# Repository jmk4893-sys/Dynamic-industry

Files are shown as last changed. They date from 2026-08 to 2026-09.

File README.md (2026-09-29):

# Dynamic-industry

Dynamic industry Development

## 태양광 셀 은(Ag) 회수 부유선별 설비

폐 태양광 모듈(c-Si)에서 박리한 셀 분획으로부터 **은(Ag)** 을 부유선별로 농축하는
설비의 설계와 계산 코드. 셀 분획을 공급하는 상류 분리설비(DG-HK60)는
[3D 운전 콘솔](docs/drawings/pv-delamination-3d.html)로 별도 정리했다.

- 평균 **0.30 t/h**, 최대 **0.50 t/h** (건조 고체 기준)
- **세척수 bias 연속 부선조 1단, Ø350 mm × 라이저 2.4 m** (대안: 기계식 러퍼·스캐빈저·클리너 3단)
- Ag 회수율 **99.7 %**, 정광 **6.36 kg/h @ 46.3 wt% Ag** (농축비 78배)
- 기액 체류시간 **1 분**, 설치 전력 **6.52 kW** (탈수 보조설비 포함)
- 황화제·pH 조정제·억제제 없음 — 약제는 포수제·촉진제·기포제 3종뿐

### 설계 근거

실증 논문 두 편의 데이터를 1차 근거로 삼고, 모델이 그 실험값을 재현하도록 보정했다.
`tests/test_references.py` 가 재현성을 검증하므로, 설계 기준을 고쳐 문헌과 어긋나면
테스트가 실패한다.

1. Saffarian, Galvin, Firouzi, *Minerals Engineering* **242** (2026) 110189 — 회분식 실증
2. Saffarian, Galvin, Firouzi, ChemRxiv preprint (2026), doi:10.26434/chemrxiv.15003814/v1 — 연속 실증

> [2] 는 프리프린트이며 저자들이 호주 가출원(No. 2025902821)을 제출한 상태다.
> 상업화 전 실시권 검토가 필요하다.

### 문서

| 문서 | 내용 |
|---|---|
| [docs/flotation-separator-design.md](docs/flotation-separator-design.md) | 설계 사양서 — 근거, 두 안, 계장·안전, 시운전 계획 |
| [docs/design-calculation.md](docs/design-calculation.md) | 설계 계산서 (코드에서 자동 생성) |
| [docs/drawings/ag-flotation-drawings.html](docs/drawings/ag-flotation-drawings.html) | **설계도 7매** — 공정 흐름도(필터프레스 라인 포함), 부선조 상세 단면도, 장치 대안 비교도, 중공축 급기 상세, 셀별 상세 3매 (브라우저로 열 것) |
| [docs/drawings/ag-flotation-3d.html](docs/drawings/ag-flotation-3d.html) | **3D 조립·분해도** — 러퍼·스캐빈저·클리너 3단 스키드 + 농축조·필터프레스, 셀당 20개 부품 분해 (브라우저로 열 것) |
| [docs/drawings/pv-delamination-3d.html](docs/drawings/pv-delamination-3d.html) | **DG-HK60 3D 운전 콘솔** — 부선 공정에 셀 분획을 공급하는 상류 분리설비. 5단 밀폐 IR 캐리지 순환, 이동 계단 칼날(SHK-101) 박리 — 셀모듈과 백시트를 유리에서 한 장으로, 일곱 조각이 따로 떠서 유리를 따라간다(칼날 모듈 추종), 15단계 공정 재생, 컷어웨이·분해도, 전기·PLC·제작도면 15종, **부품도 169장 · 모듈 조립도 13장**, 열수지 계산기 (브라우저로 열 것) |
| [docs/dg-hk60-rfq.html](docs/dg-hk60-rfq.html) | **DG-HK60 상세설계 기술사양서 (RFQ)** — 상세설계 용역 발주용. 요구성능·설계기준·기계/전기/안전 요구사항·납품물·FAT/SAT·입찰자 확인사항 16건 — 열린 15건 · OI-11 해소 (브라우저로 열 것, A4 인쇄 가능) |
| [docs/dg-hk60-fab-spec.html](docs/dg-hk60-fab-spec.html) | **DG-HK60C 제작 지침서 (FAB-001)** — 볼트 등급·체결력·조임토크, 용접 각장, 부재 판두께·재질, 기초 앵커 매입깊이·연단거리를 하중에서 유도한 문서. 접합부 11개소·부재 27종·앵커 6개소·ITP 16단계 (브라우저로 열 것, A4 인쇄 가능) |
| [docs/dg-hk60-assembly.html](docs/dg-hk60-assembly.html) | **DG-HK60C 조립 지침서 (ASM-001)** — 도면을 처음 보는 사람이 조립도·부품도만으로 세울 수 있게 쓴 문서. 안전·공구·도면 읽는 법·볼트 조이는 법·모듈 사이의 순서·모듈별 67단계 (부품 카탈로그에서 생성) |
| [docs/dg-hk60-procurement.html](docs/dg-hk60-procurement.html) | **DG-HK60C 조달 지침서 (PRC-001)** — 자재 발주표(1차원 절단 배치를 푼 정척 본수·시트 매수) · 운반 분할(세우는 순서를 따르는 차수표) · 구매품 사양 60종 (부품 카탈로그에서 생성) |
| [docs/dg-hk60-analysis.html](docs/dg-hk60-analysis.html) | **DG-HK60C 구조·열해석 보고서 (CAL-001)** — 직접강성법 프레임, 1차원 과도 열전도, **IR 뱅크 복사 유속 + 면내 2차원 전도**, **램프 지지·관통 상세**, **정상상태 열수지**, **칼날 모듈 추종**(패드 평면도가 만드는 유리 굴곡 · 몬테카를로). 닫힌해 15건으로 해석기를 검증하고 구조 14건·열 13건·IR 8건·지지 7건·수지 8건·에어록 8건을 푼 뒤, 해석이 만든 요구 26건과 **해석이 못 보는 것**을 적었다 (여섯 해석 모듈에서 생성) |
| [docs/dg-hk60-pilot.html](docs/dg-hk60-pilot.html) | **DG-HK60C 파일럿 시험 계획서 (PIL-001)** — 온도–박리력 곡선·칼날 수명·유리 수율·면내 온도 균일도·열수지. 시료 수를 요구정밀도에서 거꾸로 풀어(t 분위수·Clopper–Pearson) 총 454장·2단계로 잡았다 (계획 모델에서 생성) |
| [docs/dg-hk120-twin-cell.html](docs/dg-hk120-twin-cell.html) | **DG-HK120C 트윈 셀 검토서** — 1챔버·2분리셀(계단 칼날) 수평병렬로 처리량을 배로 올리는 안의 배치·전력·인터록 검토 (브라우저로 열 것) |

## MP-50 염수 밀도분리 파일럿 장치

폐태양광 후처리 블랙파우더에서 **EVA·백시트를 실리콘 분말로부터 걷어내는** 소형
파일럿. 세 재질의 입경이 31~75 µm 로 겹쳐 체로는 나눌 수 없으므로, 염수(NaCl
0~18 wt%)의 밀도를 세 재질의 유효밀도 사이에 놓고 나눈다. 임펠러와 급기는
**분산 수단이지 분리 수단이 아니다** — 둘을 동시에 정지시킨 뒤의 자연 부상·침강이
분리다.

- 동체 **Ø400 ID × H600**, 원뿔 60° · 전용적 **89.86 L**, 운전 장입 **61.4 L**
- 아세이 A~K **11계통 · 부품 220개**, 건조질량 **151 kg**
- 교반축 Ø25 SUS316L, Ø300 4PBT45° 임펠러 2단, 배플 4매, 콘 급기 분산링
- 제어반 J-06 — 0.55 kW VFD, 감속비 1/10, **CR1 접점 하나가 임펠러와 급기를 동시에 끊는다**

### 동시 차단은 운용 규칙이 아니라 회로다

임펠러와 급기가 몇 초라도 어긋나 멎으면 잔류 와류나 잔류 기포가 층분리를
흐트러뜨려 **정치 t=0 이 정의되지 않는다**. 그러면 DOE 의 정치시간 축이 통째로
못 쓰게 된다. 그래서 제어반은 셋을 구조로 강제한다.

- **운전 릴레이 CR1 의 접점 하나**가 VFD RUN·급기 솔레노이드·로거 t=0 마크를 함께
  문다. 버튼을 둘로 나누면 사람이 누르는 순서가 데이터에 섞인다.
- **분산시간은 타이머(TIM1)가 끊는다.** 수동 버튼은 조기 차단용으로만 병치한다 —
  조건표대로 돌리면 배치마다 분산시간이 같다.
- **VFD 정지방식은 프리런**이다. 램프 정지는 감속하는 동안에도 저어서 t=0 을 흐린다.
- 급기 솔레노이드는 **NC** 라 소자되면 닫힌다. 정전이나 배선 단선에서도 공기가
  들어가지 않는다.

감속비는 여기서 갈린다. 표준 감속비 가운데 축 150 rpm 을 낼 수 있는 것은 **1/10
뿐**이고, 1/20 은 60 Hz 에서도 87 rpm 에 그친다 — 이것이 연구문서가 적은 상한
90 rpm 의 정체로 보인다 ([`control.py`](src/mp50_separator/control.py)).

### 원본 도면 그대로는 제작이 되지 않는다

치수가 세 문서에 흩어져 있고 셋이 서로 다르다 — 연구문서 Rev.0, 도면
MP-50-P0-001, 도면 MP50-DR-000. 충돌 8건을 정리했고 그중 **2건은 그대로 두면
조립 자체가 불가능**하다.

| 번호 | 항목 | 원본 | 문제 |
|---|---|---|---|
| **C1** | 원뿔 높이 | H150 + 60° | Ø400 에서 Ø38 로 닫히지 않는다 (313.5 필요) |
| **C2** | 배플 폭 | 80 × 4매 | 안쪽 모서리 R114 가 Ø300 임펠러 팁 R150 과 **36 mm 겹쳐 축이 돌지 않는다** |

해결 근거는 [`conflicts.py`](src/mp50_separator/conflicts.py) 와 제작도면의
'원본 치수 충돌과 해결 근거' 절에 남겼다. C1 은 연구문서의 H346 을 **가상 정점높이**로
읽으면 동체 상단 Z946 · 커버 상면 Z951 · 전용적 89.9 L 가 한 원점에서 동시에
맞아떨어지므로 확정했고, C2 는 임펠러 Ø300 이 세 문서에 모두 같고 DOE·동력·Njs
모델이 그 위에 서 있으므로 배플 쪽을 35 mm 로 줄였다.

### 문서

| 문서 | 내용 |
|---|---|
| [docs/drawings/mp50-fabrication-drawings.html](docs/drawings/mp50-fabrication-drawings.html) | **제작도면 A3 17매** — 기준좌표·공차, 전체 조립도, 아세이 A~K, 동체·원뿔 전개도, 노즐표, 용접·검사 기준, **제어반 J-06 결선도 2매**. 손으로 적은 치수가 없다 (브라우저로 열 것) |
| [docs/drawings/mp50-part-drawings.html](docs/drawings/mp50-part-drawings.html) | **부품 상세도면 A3 29매** — 제작품 33종을 27장에 담았다 (소물은 합본). 장마다 소재 규격, 완성 치수, 기하공차, 표면, 가공 순서, 검사. 규격·구매품은 도면 대신 명세 한 장 (브라우저로 열 것) |
| [docs/drawings/mp50-3d.html](docs/drawings/mp50-3d.html) | **3D 분해 · 컷어웨이 · 부품 단독 보기 콘솔** — 아세이별 분해, 단면 컷어웨이, 부품 하나만 떼어 보기, 분산→동시 정지→자연 층분리 재생. 입자는 검증 모듈과 같은 Stokes 식으로 움직인다 (브라우저로 열 것) |
| [docs/cad/](docs/cad/) | **CAD 파일 — 절단 DXF 33, 가공도 DXF 33, 3D STEP 33** — 레이저 CAM 이 그대로 먹는 1:1 윤곽, A3 가공도, 해석면 솔리드. 절단 길이 합계 약 44 m |
| [docs/mp50-fabrication-spec.md](docs/mp50-fabrication-spec.md) | 제작 기준 요약 (코드에서 자동 생성) |

### 도면에서 CAD 로

HTML 부품도는 사람이 읽는 것이고, `docs/cad/` 는 **기계가 읽는 것**이다. 같은
기하에서 나오므로 둘이 어긋날 수 없다.

- `dxf/cut/` — 절단 윤곽만. 1:1, 글자 한 자 없음, 원점은 소재 왼쪽 아래.
  레이저 오퍼레이터가 열어 그대로 자른다.
- `dxf/dwg/` — A3 가공도. 틀·표제란·치수·구멍 좌표표·절곡표·주기.
- `step/` — 3D 솔리드 (AP214). 평면·원통·원뿔 **해석면**이라 CAM 이 지름과
  축을 읽는다. 메시가 아니다.

DXF 는 R12(AC1009)·cp949 라 한국 현장 CAD 가 그대로 연다. STEP 33 개 전부를
OpenCascade 로 다시 읽어 **유효 솔리드**이고 부피가 해석값과 **0.0000 %** 차인
것을 확인했다. 시험은 외부 라이브러리 없이 파일을 되읽어 윤곽 폐합, 부호 방향,
소재 수용 여부, 모서리가 정확히 두 면에 쓰였는지를 본다.

CAD 를 세우면서 부품표의 결함 두 개가 드러났다.

- **각관 질량을 둥근 관 식으로 셌다.** □40 × t2 의 단면은 304 mm² 인데 원형
  식이 π/4 를 곱해 239 mm² 로 21 % 가볍게 나왔다. 프레임 18 본이 전부 각관이라
  아세이 H 가 23.3 → 27.9 kg, 건조 총계가 145.9 → **150.6 kg** 으로 늘었다.
- **동체 세로이음이 N1 급광 노즐을 지났다.** 전개 원점을 θ0 에 두면 노즐
  구멍이 평판 끝에 걸쳐 반쪽씩 잘린다. 이음선을 노즐이 없는 **θ135°** 로
  옮겼다 — 가장 가까운 노즐까지 158 mm 떨어진다.

### 설계 검증에서 나온 것

검증 14건 중 조립 항목은 전부 통과했고, 기능 항목 2건이 WARN 이다. 둘 다
**장치가 아니라 시험계획을 고치라**는 뜻이다.

- **CHK-05** Zwietering Njs 가 135 rpm 인데 감속기 상한이 90 rpm 이라 여유가 없다 →
  최고속도 150 rpm 확보 권고 (축·동력·위험속도는 150 rpm 으로 검증했다)
- **CHK-10** 정치 600 s 로는 31 µm 백시트가 1 % 만 부상한다. Stokes 는 지름의
  제곱으로 가므로 미세분은 시간이 제곱으로 든다 → 정치시간 격자를 600~3600 s 로
  넓히고, 염도 격자에 22/26 wt% 를 넣을 것 (포화까지 올리면 상승속도 2.7 배).
  단 포화 염수까지 갈 경우 동체는 SUS304 가 아니라 SUS316L 이어야 한다.

### 사용법

```bash
PYTHONPATH=src python -m mp50_separator                          # 제작 기준 출력
PYTHONPATH=src python -m mp50_separator -o docs/mp50-fabrication-spec.md
python tools/mp50_drawings.py                                    # 아세이 제작도면 15매
python tools/mp50_parts.py                                       # 부품 상세도면 29매
```

### 구조

```
src/mp50_separator/
  geometry.py    Z 기준좌표계 · 원뿔 폐합 · 용적 · 노즐 (여기만 고치면 된다)
  components.py  아세이 A~K 부품표 — 질량은 기하에서 계산한다
  conflicts.py   원본 3종의 치수 충돌 8건과 해결 근거
  checks.py      제작성·기능성 검증 14건 (조립 / 기능)
tools/
  mp50_drawings.py   기하에서 아세이 제작도면 HTML 을 생성
  mp50_parts.py      제작품마다 부품 상세도면 HTML 을 생성
  _mp50_draft.py     ISO 128 제도 프리미티브 (두 생성기 공용)
```

도면은 둘 다 **코드에서 생성**한다. 손으로 고치면 `tests/test_mp50_drawings.py`
와 `tests/test_mp50_parts.py` 의 재생성 검사가 깨진다. 부품도는 `components.py`
의 조달 구분(제작/규격/구매/가공)을 그대로 따르므로, 제작품을 하나 추가하고
도면을 잊으면 생성 자체가 실패한다.

### 사용법

패키지가 `src/` 레이아웃이므로 설치 없이 실행할 때는 `PYTHONPATH=src` 를 붙인다.

```bash
PYTHONPATH=src python -m flotation_design                               # 계산서 출력
PYTHONPATH=src python -m flotation_design -o docs/design-calculation.md # 파일로 저장
PYTHONPATH=src python -m flotation_design --peak-tph 0.6                # 처리량 변경
python -m unittest discover -s tests -t .                               # 테스트 (1,207건)

# 부품 카탈로그 — 형상·치수·재질에서 질량과 자중을 계산한다
python3 tools/parts.py                     # 카탈로그 리포트 (품목·질량·자중 검증)
python3 tools/fab_spec.py                  # 제작 지침서 계산 근거
python3 tools/gen_parts_js.py --write      # 카탈로그 → 콘솔의 부품도·조립도 데이터
python3 tools/gen_assembly_doc.py --write  # 카탈로그 → 조립 지침서 HTML
python3 tools/procure.py                   # 조달 계산 (자재·운반·구매)
python3 tools/gen_procure_doc.py --write   # 카탈로그 → 조달 지침서 HTML

# 해석 — 형상이 바뀌면 결과가 따라 움직인다
python3 tools/fea.py                       # 구조 해석기 검증 (닫힌해 5건)
python3 tools/therm.py                     # 열 해석기 검증 (닫힌해 5건)
python3 tools/analysis_structural.py       # 구조해석 S1~S14 (S10 계단 칼날 칼끝 예산 · S12~S14 칼날 모듈 추종)
python3 tools/glass_follow.py              # 유리면 추종 — 패드 평면도 몬테카를로 · 곧은 칼날 vs 일곱 모듈 · 유리 굽힘
python3 tools/analysis_thermal.py          # 열해석 T1~T13 + 요구 R1~R6
python3 tools/analysis_irbank.py           # IR 뱅크 배치 IR1~IR8 + 요구 RIR1~RIR5
python3 tools/lampmount.py                 # 램프 지지·관통 LM1~LM7 + 요구 RLM1~RLM5
python3 tools/heatbalance.py               # 정상상태 열수지 HB1~HB8 + 요구 RHB1~RHB5
python3 tools/gen_analysis_doc.py --write  # 해석 → 보고서 HTML
python3 tools/pilot_plan.py                # 파일럿 시료 수·규모·일정
python3 tools/gen_pilot_doc.py --write     # 계획 → 시험 계획서 HTML
python3 tools/sync_fab_doc.py --write      # 제작 지침서의 파생 숫자를 계산기와 맞춤
python3 tools/knife_stepped.py             # 계단형 핫나이프 — 조각별 힘 · 물림 램프 · 사이클 · 계단 높이의 창
```

설치하면 `PYTHONPATH` 없이 쓸 수 있다.

```bash
pip install -e .
flotation-design
```

`--average-tph` / `--peak-tph` 를 바꾸면 RFC와 농축·여과 보조설비는 새 유량으로
재산정한다. 기계식 셀 동체는 `design_basis.py` 의 확정 치수를 유지해 새 처리량에서
성능을 계산하며, 목표에 미달하면 계산서에 경고와 필요 치수를 표시한다.

축약차수 입자 애니메이션은 선택 의존성을 설치해 만든다. 이는 CFD/DEM 검증이 아니라
기포 상승·입자 침강·부착/탈착을 보여주는 교육용 모델이다.

```bash
pip install -e '.[simulation]'
python tools/flotation_sim.py fc201-simulation.mp4
```

### 구조

```
src/flotation_design/
  references.py     문헌 실증값 — 설계의 1차 근거 (여기 수치는 논문에서 온 것)
  design_basis.py   설계 전제 — 급광 조성, 속도상수, 셀 사양, 약제 (여기만 고치면 됨)
  feed.py           급광 조성 · 슬러리 물성
  kinetics.py       2속도(Kelsall) 반응속도 — 속부선/지연부선/비부선, 회분식·연속
  circuit.py        흐름 추적 · 복합입자 동반 · 순환부하 수렴 (2안)
  rfc.py            flux 상사 스케일업 · bias · 연속 부선조 성능 (1안)
  sizing.py         기계식 셀 체적/형상, 로터, 급기, 정광 배출 부하
  reagents.py       약제 투입량 (고체 기준 g/t · 물 기준 ppm)
  conditioning.py   조건조 사이징
  plant.py          두 안 조립 + 농축조
  report.py         Markdown 계산서 생성
```

### 모델에서 알아둘 두 가지

**정광 품위에는 물리적 상한이 있다.** Ag 는 Si 웨이퍼에 소결된 전극이라 부상할 때
Si 코어를 달고 온다. 부상 Ag 1 kg 당 맥석 1.1 kg 이면 상한은 1/(1+1.1) = 47.6 wt%
이고, 문헌의 두 최고 품위(48.8 / 46.7 wt%)가 모두 여기서 멈췄다. 세척수로 제거되지
않으므로 **클리너를 더 붙여도 넘을 수 없다.**

**연속 부선조에는 반응속도 모델을 쓰지 않는다.** 완전혼합조가 아니므로 기액 체류시간
1분을 CSTR 식에 넣으면 Ag 회수율이 63 % 로 나와 실측(~100 %)과 맞지 않는다.
flux 상사로 스케일업하면 수력학적 조건이 보존되므로 실증 측정값을 이월한다.

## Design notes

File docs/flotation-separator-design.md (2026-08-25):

# 태양광 셀 은(Ag) 회수 부유선별 설비 설계

**목적** — 폐 태양광 모듈(c-Si)에서 박리한 셀 분획으로부터 **은(Ag)** 을 부유선별로
농축해, 후단 침출·제련 물량을 약 1/79 로 줄인다.

| 항목 | 값 |
|---|---|
| 구성 | **세척수 bias 연속 부선조 1단** (대안: 기계식 러퍼·스캐빈저·클리너 3단) |
| 평균 / 최대 처리량 | **0.30 / 0.50 t/h** (건조 고체) |
| 부선기 | **Ø350 mm × 라이저 2.4 m, 1기** |
| Ag 회수율 | **99.7 %** |
| 정광 | **6.36 kg/h @ 46.3 wt% Ag** (농축비 78배) |
| 미광 Ag 품위 | 18 g/t |
| 기액 체류시간 | **1 분** |
| 설치 전력 | **6.5 kW** (탈수 라인 포함) |

전체 계산 과정은 [설계 계산서](design-calculation.md) 에 있고, 그 계산서는
`PYTHONPATH=src python -m flotation_design` 로 코드에서 자동 생성된다.
도면은 [설계도 7매](drawings/ag-flotation-drawings.html) — 공정 흐름도(DWG-001),
부선조 상세 단면도(DWG-002), 장치 대안 비교도(DWG-003), 중공축 급기 상세(DWG-004),
러퍼·스캐빈저·클리너 셀별 상세(DWG-005~007) — 로 별도 정리했다
(브라우저로 열어야 한다).
같은 부선조를 입체로 본 [3D 컷어웨이 모델](drawings/ag-flotation-3d.html) 도 있다.

---

## 0. 이 설계는 무엇에 근거하는가

본 설계는 아래 두 편의 실증 결과를 1차 근거로 삼는다. 모델 파라미터는 이 수치를
재현하도록 보정했고, `tests/test_references.py` 22건이 재현성을 검증한다.

**[1]** H. Saffarian, K.P. Galvin, M. Firouzi, *"Rethinking silver recovery pathways in
end-of-life photovoltaic recycling using froth flotation"*, **Minerals Engineering 242
(2026) 110189** — 실회수 태양광 셀을 쓴 회분식 기계식 부선 실험.

**[2]** H. Saffarian, K.P. Galvin, M. Firouzi, *"Continuous flotation unlocks full recovery
of silver from end-of-life solar cells"*, **ChemRxiv preprint (2026-05-24)**,
doi:10.26434/chemrxiv.15003814/v1 — 세척수 bias 를 쓰는 1단 부선조의 연속 정상상태 실증.

| 출처 | 조건 | 결과 |
|---|---|---|
| [1] 1 L 회분식 러퍼 (수돗물) | 7 wt%, Jg 0.20 cm/s, 150 g/t, 3 min, 자연 pH | Ag **97.6 %**, 정광 24.0 wt% Ag, 농축비 32.2, 질량수율 2.92 % |
| [1] + 클리너 1단 (개방회로) | 동상 | Ag 86.5 %, 정광 **46.7 wt% Ag**, 농축비 62.6 |
| [2] 연속 1단, 100×80 mm | Jf 2.0 / Jg 2.0 / Jw 0.81 cm/s, 기액 체류 1 min, 2 wt% | Ag **~100 %**, 정광 **48.8 wt% Ag**, 농축비 83, 질량수율 1.25 % |

> [!IMPORTANT]
> [2] 는 심사 전 프리프린트이며, 저자들이 해당 공정에 대해 호주 가출원
> (No. 2025902821, "Recovery of silver from photovoltaic cells")을 제출한 상태다.
> **상업화 전 실시권 검토가 반드시 필요하다.** 이것이 1안의 가장 큰 사업 리스크다.

---

## 1. 이전 설계에서 무엇이 바뀌었나

문헌 없이 일반 광물부선 관행으로 추정했던 이전 판과 비교하면, 바뀐 것이 바뀌지 않은
것보다 많다. 요약하면 **이 원료는 일반 광석보다 훨씬 다루기 쉽다.**

| 항목 | 이전 설계 (추정) | 이번 설계 (문헌 근거) | 근거 |
|---|---|---|---|
| Ag 회수 상한 | 88 % (12 % Si 내부 봉입) | **97.6 %** (봉입 2.4 %) | [1] TIMA 해리도 + 극한 회수율 |
| 약제 계통 | 소다회 + 규산소다 + **Na₂S 황화** + PAX + 3418A + MIBC | **3418A + AEROFLOAT 242 + MIBC** | [1] ToF-SIMS — 포수제가 금속 Ag 에 직접 흡착 |
| pH | 9.0~9.5 조절 | **조정 없음 (자연 pH)** | [1][2] |
| 부선 속도 | k 0.45~1.2 /min, 러퍼 10 min | 1 min 에 80 %, **3 min 에 90 %** | [1] 3.2절 |
| 급기 Jg | 1.0 cm/s | **0.20~0.35 cm/s** (기계식) | [1] |
| 급광 Cu | 8 wt% (부산물) | **0.013 wt%** (미량 원소) | [1] Table 2 — 리본은 상류에서 제거 |
| 급광 Ag | 0.45 wt% | **0.59 wt%** | [2] assay |
| 정광 품위 | 2.8 wt% Ag | **46.3 wt% Ag** | 복합입자 상한 (§2) |
| 정광 mass pull | 12 % | **1.3 %** | [2] |

**황화 계통이 통째로 사라진 것**이 가장 큰 변화다. Na₂S 가 없어지면서 H₂S 위험,
pH 하한 인터록, ORP 제어 루프, 소다회·규산소다 저장·조제 설비가 함께 없어졌다.
잔티에이트(PAX)도 빠지면서 CS₂ 위험도 사라졌다. 남은 약제는 세 가지뿐이다.

---

## 2. 정광 품위의 물리적 상한 — 설계의 핵심

Ag 는 순수 입자가 아니라 Si 웨이퍼에 소결된 전면 전극이다. 표면이 소수성이 되어
부상해도 **Si 코어를 함께 끌고 올라간다.**

부상 Ag 1 kg 당 같은 입자 안에 잠긴 맥석을 **1.1 kg** 으로 두면 정광 품위의 상한은

```
1 / (1 + 1.1) = 47.6 wt% Ag
```

이 한 줄이 문헌의 두 최고 품위를 모두 설명한다 — [2] 연속 정광 **48.8 wt%**,
[1] 러퍼+클리너 정광 **46.7 wt%**. 둘 다 47 % 부근에서 멈췄다.

계산에서는 이 맥석을 `Ag_locked_gangue`라는 **보존 성분**으로 급광에 한 번만 넣고,
Ag와 같은 속도분획으로 각 단을 통과시킨다. 단계마다 새 맥석을 더하는 방식이 아니므로
폐회로에서도 질량수지가 보존된다. 이 동반분은 수분 동반(entrainment)과 달리 세척수로
제거되지 않는다. 같은 입자의 일부이기 때문이다. 따라서:

- 클리너를 몇 단 더 붙여도 47 wt% 를 넘을 수 없다. **클리너 증설은 헛수고다.**
- 품위를 더 올리려면 부선이 아니라 **분쇄를 더 하거나(해리도 향상)** 후단 습식제련으로
  가야 한다.
- 1안과 2안의 정광 품위가 46.3 % 대 45.2 % 로 사실상 같은 것도 이 때문이다.
  **품위는 장치가 아니라 원료의 성질로 결정된다.**

거꾸로 보면, 45~46 wt% Ag 정광은 이미 **제련소 직송을 검토할 수 있는 품위**다 [1].

---

## 3. 왜 부유선별인가

| 방식 | Ag-Si 복합입자에 대한 거동 | 판정 |
|---|---|---|
| 비중선별 | 복합입자 겉보기 비중이 Si(2.33)에 가까워 분리 불가 | ✗ |
| 자력/와전류 | Ag 는 비자성, 미립에서 와전류 분리 하한 미달 | ✗ |
| **부유선별** | **입자 표면의 젖음성으로 분리 — Ag 가 노출되면 Si 코어째 부상** | **✓** |
| 직접 침출 | 가능하나 전량(0.5 t/h)을 HNO₃ 로 처리 → 시약·폐액 부담 과다 | △ (후단) |

부선은 완전 해리를 요구하지 않는다. [1] 의 TIMA 분석에서 **>90 % 해리된 Ag 는 20 %,
>60 % 해리는 61 %** 에 불과한데도 회수율이 97.6 % 나오는 이유가 이것이다. 표면에 Ag 가
조금이라도 드러나 있으면 포수제가 붙고, 붙으면 뜬다.

핵심은 **포수제 화학**이다. AEROPHINE 3418A (sodium diisobutyl dithiophosphinate)는
황화 전처리 없이 금속 Ag 표면에 직접 선택 흡착한다. [1] 의 ToF-SIMS 에서 Ag 전극 위
포수제 신호가 주변 대비 **약 100배**로 나타났다.

---

## 4. 급광 사양

| 항목 | 값 | 근거 |
|---|---|---|
| 원료 | 박리된 c-Si 셀 분획, 습식 로드밀 분쇄 | [1][2] |
| 급광 입도 P80 | **66 µm** | [2] |
| 설계 고체 농도 | **7 wt%** | [1] 회분식 검증값 |
| 고체 평균 비중 | 2.374 | 조성 가중 |
| pH | 조정 없음 | [1][2] |

| 성분 | 질량분율 | 품위 | 속부선 | 지연부선 | 비부선 | k_fast | k_slow |
|---|---|---|---|---|---|---|---|
| Si | 88.20 % | — | — | — | 100 % | — | — |
| Al | 10.00 % | — | — | — | 100 % | — | — |
| **Ag** | **0.590 %** | **5,900 g/t** | 82 % | 16 % | **2 %** | 2.60 | 0.30 |
| Pb | 0.096 % | 960 g/t | 15 % | 10 % | 75 % | 1.50 | 0.25 |
| Cu | 0.013 % | 130 g/t | 68 % | 22 % | 10 % | 2.20 | 0.30 |
| 기타 | 1.101 % | — | — | — | 100 % | — | — |

속도상수는 **회분식 기준**이며, 기계식 연속 셀에는 스케일업 계수 0.8 을 곱해 쓴다.

### 규모에 대한 현실 점검

셀 분획은 모듈 질량의 **약 4.7 %** 다 [2]. 따라서 0.30 / 0.50 t/h 의 셀 분획은
**모듈 기준 6.4 / 10.6 t/h** 에 해당한다. 연 8,000 시간이면 51,000 ~ 85,000 t/yr —
국가 단위 PV 재활용 설비 규모다.

[2] 의 저자들도 "웨이퍼를 백시트에서 떼어내는 공정이 현재의 율속 단계"라고 명시했다.
**본 부선 설비는 병목이 아니다.** 병목은 상류 박리 공정이며, 설비 투자 판단은 거기서
갈린다.

---

## 5. 1안 (주설계) — 세척수 bias 연속 부선조 1단

### 5.1 왜 이 형식인가

[2] 의 연속 실증은 기계식 셀이 아니라 **세척수(wash water)로 양(+)의 bias 를 거는
수직 부선조**에서 수행됐다. 논문이 장치 형식을 명시하진 않았으나, 인용 문헌
(Reflux Flotation Cell 계열)과 운전 변수(스파저, 세척수 flux, bias, 기액 체류시간,
경사판)로 볼 때 RFC 계열 장치로 판단된다.

이 장치의 설계 변수는 **체적이 아니라 단면적 기준 flux** 다.

```
Jf = Q_feed / A     급광 flux      2.0 cm/s
Jg = Q_air  / A     기체 flux      2.0 cm/s
Jw = Q_wash / A     세척수 flux    0.81 cm/s
Jb = Jw - Jo        bias flux      양수 = 거품층 하향 순유량
```

거품층을 아래로 지나는 순 하향류가 동반 맥석을 씻어내리므로, **기계식 셀의 러퍼+클리너
2단이 하는 일을 1단에서 해낸다.** 실증에서 맥석 회수율은 0.64 % 로 회분식 기계식
셀(2.2 %)의 약 1/3.5 였다.

### 5.2 스케일업 — flux 상사

실증 flux 를 그대로 두고 **단면적만 처리량에 비례해 키운다.** 그러면 기액 체류시간과
bias 조건이 보존되므로, 실증에서 확인된 분리 성능이 그대로 이월된다.

| 항목 | 값 |
|---|---|
| **동체 내경** | **Ø350 mm** (단면적 0.0962 m²) |
| 라이저 높이 | 2.40 m (기액 체류시간 1 분 유지) |
| 라이저 체적 | 0.231 m³ |
| bias flux | 0.25 cm/s |
| 경사판 | 70° / 간격 12 mm — 미광부 침강 강화 |
| 기포 크기 | 0.5 ~ 1.0 mm |
| 송풍기 | 0.37 kW, 6.9 m³/h @ 60 kPa |

| 운전점 | 고체 농도 | 급광 flux | 급광 | 공기 | 세척수 | 월류수 | 기액 체류 |
|---|---|---|---|---|---|---|---|
| 평균 0.30 t/h | **4.22 wt%** | 2.00 cm/s | 6.93 m³/h | 6.93 | 2.81 | 1.94 | 1.00 min |
| 최대 0.50 t/h | **6.93 wt%** | 2.00 cm/s | 6.93 m³/h | 6.93 | 2.81 | 1.94 | 1.00 min |

문헌 성능을 이월하려면 급광·공기·세척수 flux와 1분 기액 체류를 함께 유지해야 한다.
따라서 평균 부하에서는 고체 투입량만 줄이고 물 유량은 유지해 농도가 4.22 wt%로
낮아진다. 고체 7 wt%를 그대로 유지하며 세 유량을 60%로 줄이는 운전은 기액 체류를
늘려 문헌과 다른 수력 조건이 되므로 동등 성능으로 간주하지 않는다.

### 5.3 고농도 운전 여유

같은 Ø350 mm 동체의 처리능력은 고체 농도에 거의 비례한다.

| 고체 농도 | 처리능력 | 검증 상태 |
|---|---|---|
| 7 wt% (**설계점**) | 0.51 t/h | [1] 회분식 검증 |
| 15 wt% | 1.14 t/h | 미검증 |
| 30 wt% | 2.51 t/h | [2] 저자 주장 (Cu 황화광으로만 실증) |

**설계는 검증된 7 wt% 에 둔다.** 30 wt% 가 PV 원료로 확인되면 같은 설비로 5배
처리량이 나오지만, 그 가정 위에 설비를 짓지는 않는다. 시운전 단계에서 고체 농도를
단계적으로 올려 확인하는 것을 시험 계획에 넣었다 (§8).

### 5.4 성능 (최대 0.50 t/h)

| 성분 | 급광 (kg/h) | 정광 (kg/h) | 미광 (kg/h) | 회수율 | 정광 품위 |
|---|---|---|---|---|---|
| Si (자유 맥석) | 437.76 | 0.00 | 437.76 | 0.00 % | 0.0 % |
| Ag 잠금 맥석 | 3.25 | 3.24 | 0.01 | 99.7 % | 50.9 % |
| Al | 50.00 | 0.00 | 50.00 | 0.00 % | 0.0 % |
| **Ag** | **2.95** | **2.94** | **0.01** | **99.7 %** | **46.3 %** |
| Pb | 0.48 | 0.12 | 0.36 | 25.5 % | 1.9 % |
| Cu | 0.065 | 0.060 | 0.005 | 91.8 % | 0.9 % |
| 기타 | 5.51 | 0.00 | 5.51 | 0.00 % | 0.0 % |
| **합계** | **500.0** | **6.36** | **493.6** | **1.27 %** (질량수율) | 100 % |

- **Ag 회수율 99.7 %**, 미광 품위 18 g/t
- 정광 **6.36 kg/h @ 46.3 wt% Ag** — Ag 2.94 kg/h
- 후단 침출 물량 **약 1/79**

평균 0.30 t/h 에서는 고체 농도를 낮춰 flux와 체류시간을 유지하므로 분리 조건이
동일하고 성능도 같다(정광 3.82 kg/h, Ag 1.76 kg/h).

### 5.5 부대 설비

| 기기 | 역할 | 사양 |
|---|---|---|
| CT-1 | 포수제 + 촉진제 조건조 (5 min) | 0.70 m³, Ø906 × 1,087 mm, 교반 0.75 kW |
| TK-101 | 미광 농축 · 공정수 회수 | 월류 6.98 m³/h, Ø3.0 m |
| TK-102 | 정광 농축 (여과 전단) | 월류 1.9 m³/h, Ø1.5 m |
| FL-101 | 정광 필터프레스 | 470 mm × 6 챔버, 2.25 m², 0.75 kW |
| FL-102 | 미광 필터프레스 | 800 mm × 43 챔버, 46.78 m², 2.2 kW |
| P-101 / P-102 | 급광 / 미광 펌프 | 1.5 / 0.75 kW |

**설치 전력 6.52 kW**. 농축조 월류 8.91 m³/h와 필터 여액 0.47 m³/h, 합계
**9.38 m³/h**를 회수한다. 월류 중 0.89 m³/h(10%)는 용존물 축적 방지를 위해
블리드하고, 케이크 수분을 포함한 순수 보충수는 **1.03 m³/h**다. 여액은 블리드하지
않고 급광으로 직접 되돌린다. 상세는 [§5.6](#56-탈수-라인-필터프레스) 참조.

물 사용량이 커 보이지만 거의 전량 순환한다. 7 wt% 라는 낮은 고체 농도가 물 회수
설비를 크게 만드는 유일한 대가이며, 고농도 운전이 검증되면 이 부담도 함께 줄어든다.

### 5.6 탈수 라인 (필터프레스)

부선 산물은 둘 다 슬러리다. 정광은 제련·침출로 보내려면 운반 가능한 케이크여야 하고,
미광은 건식 적치해야 하며 실은 그쪽이 물량이 훨씬 크다. 두 흐름 모두 **농축조 →
필터프레스** 순으로 처리한다. 농축조는 물의 90 %를 값싸게 뽑아내는 단계이고,
필터프레스는 남은 물을 압착으로 짜내는 단계다.

| 항목 | FL-101 정광 | FL-102 미광 |
|---|---|---|
| 급광 고체 | 6.36 kg/h | 493.64 kg/h |
| 급광 농도 (농축조 U/F) | 40 wt% | 45 wt% |
| 여과판 | 470 × 470 mm × 6 챔버 | 800 × 800 mm × 43 챔버 |
| 여과 면적 | **2.25 m²** | **46.78 m²** |
| 사이클 | 480 min (3 회/일) | 120 min (12 회/일) |
| 케이크 함수율 | 18 wt% | 22 wt% |
| 케이크 생산량 | 7.8 kg/h | 632.9 kg/h |
| 급광 펌프 | 0.75 kW | 2.2 kW |
| 규격 결정 기준 | 상용 최소 기종 | 챔버 용적 |

두 기기는 **서로 다른 기준으로 규격이 정해진다.** 미광기는 사이클당 담아야 할
케이크 부피가 챔버 총용적을 결정하고(702 L), 여기서 판 크기와 매수가 나온다.
정광기는 계산상 필요한 면적이 0.1 m² 도 되지 않아 어떤 여과 속도 기준으로도
규격이 잡히지 않는다 — **상용 최소 기종**(470 mm × 6 챔버)이 하한이며, 실제로는
8 시간에 한 번만 돌리고 케이크가 얇게 깔릴 뿐이다. 그래도 정광을 미광기와 섞을 수는
없으므로 별도 소형기를 둔다. Ag 46.3 wt% 짜리 케이크와 18 g/t 짜리 케이크를 같은
여포에 통과시키면 교차오염 손실이 회수한 은보다 클 수 있다.

여액 0.47 m³/h 는 공정수 탱크를 거치지 않고 **부선 회로의 첫 단으로 직접 되돌린다**
(1안은 CT-1 조건조 = FC-101 급광, 2안은 FC-201 러퍼 급광). 여포를 빠져나온
미립자가 여액에 남아 있는데, 공정수로 희석해 버리면 그 안의 Ag 를 그대로 잃는다.
첫 단으로 돌리면 한 번 더 부선 기회를 얻는다. 유량이 급광 대비 7 % 수준이라
회로 수력 부하에 주는 영향은 무시할 만하다.

---

## 6. 2안 (대안) — 기계식 러퍼 · 스캐빈저 · 클리너 3단

범용 장비로 구성해야 하거나 1안의 실시권 리스크를 피해야 할 때의 대안이다.
한 스키드 위에 원통형 셀 3기를 세운다.

```
신급광 → CT-1 → FC-201 러퍼 ─정광→ FC-203 클리너 ─정광→ 최종 정광
                    │                    │
                    미광                  미광 ─┐
                    ↓                          │
              FC-202 스캐빈저 ─정광─────────────┤ 러퍼 급광으로 순환
                    │                          │
                    미광 → 최종 미광            ┘
```

| 항목 | FC-201 러퍼 | FC-202 스캐빈저 | FC-203 클리너 |
|---|---|---|---|
| 내부 치수 | Ø1,000 × 1,300 mm | **Ø1,000 × 1,300 mm (러퍼와 공용)** | Ø400 × 650 mm |
| 거품층 | 75 mm | **50 mm** (얕게 — 회수 우선) | **150 mm** (깊게 — 배수 유도) |
| 로터 | Ø350 mm, 290 rpm | Ø350 mm, 290 rpm | Ø140 mm, 610 rpm |
| 모터 | 4.0 kW | 4.0 kW | 0.37 kW |
| 설계 Jg | 0.30 cm/s | **0.34 cm/s** | 0.20 cm/s |
| 체류시간 (최대유량) | 6.53 min | **7.09 min** | 6.92 min |
| 급광 | 7.14 m³/h | 6.72 m³/h | 0.42 m³/h (5 wt% 희석) |
| 단 Ag 회수율 | 84.1 % | 65.5 % | 88.2 % |
| **중공축 보어 / 외경** | **Ø20 / Ø60 mm** | **Ø20 / Ø60 mm** | **Ø10 / Ø50 mm** |
| 허브 토출구 | 8×Ø5 mm | 8×Ø5 mm | 8×Ø3 mm |
| 축 길이 · 내부 공기 유속 | 1.85 m · 11.2 m/s | 1.85 m · 12.5 m/s | 1.20 m · 5.6 m/s |
| 급기 압력손실 | 6.8 kPa | 7.0 kPa | 6.1 kPa |
| 1차 위험속도 / 운전속도비 | 480 rpm / 1.65 | 480 rpm / 1.65 | 1,161 rpm / 1.90 |
| 정적 처짐 | 4.72 mm | 4.72 mm | 0.89 mm |

송풍기 공용 0.55 kW (28 m³/h @ 25 kPa), 미광 농축조 TK-201 Ø2.5 m,
정광 농축조 TK-202 Ø1.0 m, 탈수 라인 FL-201 / FL-202. **설치 전력 15.07 kW.**

### 중공축 급기 — 스파저를 쓰지 않는 이유

급기는 셀 바닥의 별도 스파저가 아니라 **로터 축 내부**로 넣는다. 축 상단
로터리 조인트 → 축 보어 → 로터 허브의 분산구 8개 순으로 흘러, 공기가 나오는
바로 그 자리에서 로터 날개가 기포를 부순다. 기포가 잘고 균일해지고, 셀 바닥에
막힐 부품이 없어진다 — 태양광 셀 분쇄물처럼 미분이 많은 급광에서는 스파저
공극 막힘이 실제 운전 리스크다.

**보어는 유속으로, 외경은 진동으로 정해진다.** 보어는 축 내부 공기 유속을
18 m/s 이하가 되도록 표준 계열에서 고른다 — 너무 가늘면 압력손실이 커진다.
외경은 서비스계수 2.0을 적용한 비틀림 강도와 외팔보 예비 로터동역학 중 큰 쪽으로
정한다. 로터 집중질량과 축 분포질량을 포함한 1차 굽힘 위험속도비 ≥1.5 및 정적 처짐
≤5 mm를 동시에 확인했으며, 세 셀 모두 **로터동역학**이 외경을 정했다.
전단응력은 허용치 40 MPa보다 충분히 낮다.
부선기 축은 길고 가늘어 **강도보다 진동이 먼저 한계**가 된다.

이는 제작 전 예비검산이다. 최종 베어링 스팬, 축단 지지조건, 로터 불평형과 키홈
응력집중이 확정되면 회전체 업체의 위험속도·밸런싱 계산으로 다시 승인해야 한다.

송풍기 토출압은 펄프 수두(최대 11.44 kPa)에 축 보어·조인트·허브 토출구 손실
(최대 6.80 kPa)을 더하고 운전 여유를 두어 **25 kPa**로 잡았다. 별도 스파저가
없으므로 스파저 압력손실 15 kPa는 적용하지 않았다.

### 탈수 라인

미광은 TK-201 Ø2.5 m, 정광은 TK-202 Ø1.0 m에서 각각 농축한 뒤 전용
필터프레스로 보낸다.
FL-201 정광기 470 mm × 6 챔버 (2.25 m², 케이크 7.4 kg/h), FL-202 미광기
800 mm × 43 챔버 (46.78 m², 케이크 633.2 kg/h). **여액 0.47 m³/h 는 FC-201 러퍼
급광으로 직접 순환한다** — 여포를 빠져나온 미립 Ag 에 한 번 더 부선 기회를 주기
위해서다. 농축조 월류 5.84 m³/h와 여액을 합쳐 회수하는 물은 **6.31 m³/h**다.
월류 블리드 0.58 m³/h와 케이크 수분을 보충하는 순수 사용량은 **0.72 m³/h**다.
상세 근거는 [§5.6](#56-탈수-라인-필터프레스) 과 같다.

**성능 (최대 0.50 t/h):** Ag **93.1 %**, 정광 6.08 kg/h @ **45.2 wt% Ag**,
미광 411 g/t, 정광 질량회수율 1.22 %, 순환부하 4.22 %.
평균 0.30 t/h 에서는 Ag 95.7 %.

### 러퍼와 스캐빈저를 같은 규격으로 수정한 이유

첨부 문헌은 3분 러퍼 시험과 러퍼-클리너 시험만 수행했으며, 스캐빈저 단독 시험이나
8분 체류시간의 실증 근거는 제시하지 않았다. 따라서 이전 설계의 Ø1,050 × 1,450 mm
스캐빈저는 검증값이 아니라 보수적 가정이었다. 기본설계에서는 제작비·예비품·정비성을
고려해 러퍼와 스캐빈저 동체, 로터, 구동부 및 중공축을 공용화했다.

스캐빈저는 러퍼 미광에 남은 지연부선 분획을 회수하므로 운전조건은 다르다. 거품층을
75 mm가 아니라 50 mm로 얕게 하고 Jg를 0.34 cm/s로 높인다. 그 결과 같은 동체에서도
유효 슬러리 체적은 0.794 m³로 러퍼의 0.778 m³보다 약간 크며, 최대 유량 실제 체류시간도
7.09분으로 러퍼의 6.53분보다 길다. 포수제 추가 투입은 실증 근거가 없어 적용하지 않았다.
locked-cycle 시험에서 추가 체류시간의 이득이 확인될 때만 예비 공간에 2차 스캐빈저를
직렬 증설한다.

스캐빈저 1기가 회로 Ag 회수율을 **84.2 % → 93.1 %** 로 올린다. 미광 손실은
940 → 411 g/t로 줄어든다.

> 이전 판에서는 러퍼 뱅크 2기 + 클리너 구성으로 스캐빈저를 두지 않았다.
> 러퍼 미광에 회수할 것이 거의 없다고 본 판단이 **과했다** — 실제로 계산해 보면
> 스캐빈저 단독 회수율이 65.5 %이고 회로 기여는 +8.9 %p다.

### 배치

클리너는 낮은 가대(y 0.46 m)에 놓아 **러퍼 정광이 자연유하**하게 했다.
러퍼·스캐빈저는 0.55 m 가대 위에 선다. 되돌리는 두 흐름(스캐빈저 정광, 클리너 미광)만
순환 펌프로 올린다. 스키드는 약 5.3 × 2.9 m.

입체 형상과 부품 구성은 [3D 조립·분해도](drawings/ag-flotation-3d.html) 참조 —
셀당 20개 부품(중공축·로터리 조인트 포함)에 배관·농축조·필터프레스 12개를 더해
분해해 볼 수 있다.

---

## 7. 두 안 비교와 권고

| 지표 | 1안 연속 부선조 | 2안 기계식 3단 | 판정 |
|---|---|---|---|
| Ag 회수율 | **99.7 %** | 93.1 % | 1안 **+6.6 %p** |
| Ag 정광 품위 | 46.3 wt% | 45.2 wt% | 동등 (복합입자 상한) |
| Ag 미광 손실 | **18 g/t** | 411 g/t | 1안 우위 |
| 부선기 대수 | **1기** | 3기 | 1안 |
| 설치 전력 | **6.52 kW** | 15.07 kW | 1안 57 % 절감 |
| 부선기 설치 면적 | Ø350 mm × 3.9 m(H) | 스키드 5.3 × 2.9 m | 1안 |
| 체류시간 | **1 min** (기액) | 6.53 + 7.09 + 6.92 min | 1안 |
| 순환류 | 없음 | 4.22 % | 1안 |
| 기술 성숙도 | TRL 5 (연속 90 min 실증) | 범용 장비, 회분식만 실증 | 2안이 조달 유리 |
| 지식재산 | **가출원 대상 — 실시권 필요** | 제약 없음 | 2안이 유리 |

**권고 — 1안.** 회수율이 6.6 %p 높고 전력은 57 % 낮으며 장치가 1기다.

정광 품위가 두 안에서 같다는 점을 유념할 것. 품위는 장치가 아니라 **원료의 복합입자
성질**로 결정되므로, 장치 선정으로 개선할 수 있는 것은 회수율·전력·설치면적뿐이다.

**다만 1안은 특정 장치 형식에 의존하고 특허 가출원 대상이다.** 실시권 협상이
불발되거나 장치 조달이 어렵다면 2안이 현실적 차선이며, 계산상 성능 손실은 회수율
6.6 %p다. 이 수치는 실제 원료 잠금사이클 시험으로 확정해야 한다.

---

## 8. 약제 계통

**pH 조정제·황화제·억제제를 쓰지 않는다.** 남은 것은 세 가지뿐이다.

| 약제 | 역할 | 투입량 | 조제 | 펌프 (최대) | 투입 지점 |
|---|---|---|---|---|---|
| AEROPHINE 3418A | 포수제 | 300 g/t | 10 % | 1.47 L/h | CT-1 |
| AEROFLOAT 242 | 촉진제 | 300 g/t | 10 % | 1.47 L/h | CT-1 |
| MIBC | 기포제 | 30 ppm (물 기준) | 원액 | 0.25 L/h | 급광박스 |

**투입량 300 g/t 는 습식 분쇄 원료 기준이다.** [2] 에 따르면 건조 원료의 최적치는
150 g/t 였으나, 습식 분쇄물은 거품 형성이 부족해 2배가 필요했다. 실기는 습식
분쇄물을 그대로 쓰므로 300 g/t 가 설계값이다.

**기포제는 물 기준(ppm)으로 관리한다.** 거품 안정성은 수상 농도로 결정되기 때문이다.
7 wt% 운전에서는 t 당 환산 399 g/t 이지만, 30 wt% 로 올리면 t 당 소요량이 1/6 로
줄어든다 — 고농도 운전의 부수적 이득이다. MIBC 는 수용해도가 약 17 g/L 라 희석하면
정량펌프 유량이 20 L/h 까지 커지므로 **원액 투입**하고 검량통을 단다.

---

## 9. 계장·제어 및 안전

### 제어 루프 (1안)

| 태그 | 계측/제어 | 설정 | 동작 |
|---|---|---|---|
| FIC-101 | 급광 유량 | 처리량 비례 | 급광 펌프 VFD |
| DIC-102 | 급광 밀도 | 7 wt% | 희석수 밸브 |
| FIC-103 | 급기 유량 | Jg = Jf (1:1) | 제어밸브 — 급광 flux 에 연동 |
| FIC-104 | **세척수 유량** | Jw/Jf = 0.405 | 제어밸브 — 급광 flux 에 연동 |
| LIC-105 | 계면 높이 (거품/펄프) | — | 미광 배출 밸브 |
| **FFIC-106** | **bias 연산** | Jb = Jw − Jo ≥ 0.20 cm/s | 세척수·미광 배출 협조 제어 |
| FQ-107~109 | 약제 정량펌프 3대 | 급광량 비례 | — |

**bias 제어가 이 설비의 전부다.** bias 가 음수로 넘어가면 세척 효과가 사라져 정광
품위가 무너지고, 과도하면 회수율이 떨어진다. 세척수 유량과 미광 배출 유량을 함께
잡아 bias 를 직접 연산·제어해야 한다. 기계식 셀의 액면 제어와는 성격이 다르다.

### 인터록

1. bias < 0 → 경보, 세척수 증량 또는 미광 배출 감량
2. 급광 정지 → 급기·세척수·약제 정량펌프 순차 정지
3. 계면 HH → 급광 정지
4. 정광 여과기 만액 → 급광 정지

### 안전

이전 설계 대비 **위험이 크게 줄었다.**

| 위험 | 상태 | 대책 |
|---|---|---|
| ~~H₂S 중독~~ | **없어짐** (Na₂S 미사용) | — |
| ~~CS₂ (잔티에이트 분해)~~ | **없어짐** (PAX 미사용) | — |
| Si 분진 폭발 | 잔존 | **전 공정 습식**, 정광·미광 함수율 15 % 이상 유지 |
| Pb 노출 | 잔존 — 정광에 1.9 wt% 로 농축 | 습식 취급, 정광 취급 시 호흡보호구, 혈중 납 검진 |
| 고가 정광 | 잔존 — Ag 45~46 wt%, **2.9 kg Ag/h** | 정광 배출부 시건, 교대별 계량·정산, CCTV |
| 티오계 약제 | 잔존 | 피부·호흡 노출 방지, SDS 비치, 약제실 환기 |

정광의 Ag 함량이 45~46 wt%라는 점을 가볍게 보지 말 것. 시간당 2.9 kg의 은이
한 곳으로 모인다. **물리적 보안과 계량 정산 절차가 공정 설계의 일부다.**

---

## 10. 시운전 및 성능 확인 계획

모델은 문헌값을 8 % 이내로 재현하지만, 문헌의 원료와 실제 원료는 다를 수 있다.

| 단계 | 시험 | 산출물 |
|---|---|---|
| 1 | 실제 급광 assay (ICP-MS + 파이어애세이 대조), TIMA 해리도 | `design_basis.CELL_FRACTION` 갱신 |
| 2 | 1 L 회분식, 정광 30초 간격 분취 (0.5·1·2·3·6 min) | 2속도 속도상수 재보정 |
| 3 | 약제 투입량 최적화 (75~600 g/t), **습식/건조 원료 비교** | 300 g/t 검증 |
| 4 | **연속 파일럿 — 고체 농도 단계 상승 (7 → 15 → 30 wt%)** | 고농도 운전 가부 확정 → 동체 재산정 |
| 5 | bias 민감도 (Jb 0.1 ~ 0.4 cm/s) | 품위-회수율 균형점 확정 |
| 6 | 코드 재실행 | 갱신된 계산서 |
| 7 | 실기 72시간 연속 시운전 (0.3 / 0.4 / 0.5 t/h) | 성능 보증 |

**4단계가 가장 중요하다.** 고체 농도 30 wt% 가 PV 원료로 확인되면 같은 Ø350 mm
동체로 2.5 t/h 가 나온다 — 설비를 5배 키운 것과 같다. 반대로 7 wt% 를 넘기지 못하면
물 회수 설비 부담이 그대로 남는다. **이 한 가지 시험이 설비 경제성을 좌우한다.**

### 성능 보증값 (제안)

| 항목 | 보증값 | 조건 |
|---|---|---|
| Ag 회수율 | ≥ 95 % | 급광 0.5 t/h, P80 66 µm, 7 wt% |
| 정광 Ag 품위 | ≥ 40 wt% | 동일 |
| 정광 mass pull | ≤ 2 % | 동일 |
| 미광 Ag 품위 | ≤ 300 g/t | 동일 |
| 가동률 | ≥ 95 % | 계획정비 제외 |

보증값을 실증값(99.7 %)보다 낮게 잡은 것은 원료 변동과 상류 박리 품질 편차를
감안한 것이다.

### 안정화 대기 시간

성능 측정은 기동 직후가 아니라 회로가 정상상태에 든 뒤 시작해야 한다.
2안 3단 회로의 기동 과도응답을 CSTR 연립 ODE 로 적분하면 (계산서 §7.2)
**회수율의 95 % 도달에 약 7분, 99 % 에 약 12분**이 걸린다 — 순환류(스캐빈저
정광·클리너 미광)가 안정되는 시간도 같은 규모다. 시험 프로토콜에는 여유를
실어 **기동 후 30분 대기**를 권고한다. 기포-입자 수력학 검산(계산서 §7.1)은
설계 속도상수가 Yoon-Luttrell 충돌 효율과 문헌 범위의 부착 효율(Ea 0.11~0.19)
로 재현됨을 확인했다.

기포·입자 애니메이션은 `pip install -e '.[simulation]'` 후
`python tools/flotation_sim.py fc201-simulation.mp4`로 재생성할 수 있다. 셀 치수,
기포 상승속도와 기동 곡선을 설계 코드에서 직접 읽는다. 다만 충돌·부착·탈착 확률은
시각화를 위한 경험계수이므로 이 도구는 **CFD/DEM 검증이 아니라 축약차수 교육용
모델**이다. 제작 승인에는 다상 CFD/입자 추적과 파일럿 시험이 별도로 필요하다.

---

## 11. 코드로 재계산하기

패키지가 `src/` 레이아웃이므로 설치 없이 실행할 때는 `PYTHONPATH=src` 를 붙인다
(`pip install -e .` 로 설치했다면 `flotation-design` 으로 바로 실행).

```bash
PYTHONPATH=src python -m flotation_design                               # 계산서 표준출력
PYTHONPATH=src python -m flotation_design -o docs/design-calculation.md # 파일로 저장
PYTHONPATH=src python -m flotation_design --peak-tph 0.6                # 처리량 변경
python -m unittest discover -s tests -t .                               # 검증 (286건)
```

설계 전제는 모두 `src/flotation_design/design_basis.py` 한 곳에, 문헌 실증값은
`src/flotation_design/references.py` 에 있다. 시험 결과가 나오면 전자를 갱신하고
재실행하면 동체 치수부터 약제 소요량까지 일관되게 다시 계산되며,
`tests/test_references.py` 가 문헌과의 정합성을 계속 지켜준다.

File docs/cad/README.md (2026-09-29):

# MP-50 CAD 파일

`python tools/mp50_cad.py` 가 만든다. 손으로 고치지 말 것 — 다시 생성하면 덮어쓴다. 좌표는 모두 `mp50_separator` 의 확정 기하에서 나온다.

| 폴더 | 무엇 | 쓰는 곳 |
|---|---|---|
| `dxf/cut/` | 절단 윤곽만. 1:1, 글자 없음, 원점은 소재 왼쪽 아래 | 레이저·워터젯 CAM |
| `dxf/dwg/` | A3 가공도. 틀·표제란·치수·구멍표·주기 | 현장 인쇄 |
| `step/` | 3D 솔리드 (AP214). 평면·원통·원뿔 해석면 | 기계가공·간섭 확인 |

DXF 는 R12(AC1009) 이고 글자는 cp949 다 — 한국 현장 CAD 가 그대로 읽는다. STEP 은 AP214 이며 OpenCascade 로 부피와 다양체를 확인했다.

## 부품

| 부품 | 품명 | 재질 | 수 | 형상 | 소재 | 윤곽 mm | 절단 mm | 면적 mm² | 질량 kg | 3D |
|---|---|---|---|---|---|---|---|---|---|---|
| `A-01` | 동체 (Shell) | SUS304 | 1 | 전개 | SUS304 2B t3 판재 1300 × 620 | 1266.1 × 600.0 | 4526 | 748346 | 18.072 | O |
| `A-02` | 원뿔 (Cone) | SUS304 | 1 | 전개 | SUS304 2B t3 판재 820 × 420 | 800.0 × 400.0 | 2125 | 245766 | 5.911 | O |
| `A-03` | 배출 스터브 | SUS316L | 1 | 관재 | SUS316L Ø63.5 × t2.0 위생튜브 L60 + 2" 페룰 | 63.5 × 63.5 | 386 | 386 | 0.124 | O |
| `A-04` | 동체 노즐 | SUS316L | 9 | 관재 | SUS316L 위생튜브 (호칭별) + 페룰 | 12.7 × 12.7 | 69 | 57 | 0.034 | O |
| `A-05` | 상단 플랜지 | SUS304 | 1 | 판재 | SUS304 t10 판재 Ø500 | 480.0 × 480.0 | 3311 | 49647 | 3.937 | O |
| `A-06` | 지지링 | SUS304 | 1 | 판재 | SUS304 t8 판재 Ø500 | 480.0 × 480.0 | 2959 | 50878 | 3.228 | O |
| `A-07` | 보강 거싯 | SUS304 | 4 | 판재 | SUS304 t5 판재 110 × 110 | 97.2 × 97.2 | 331 | 4989 | 0.198 | O |
| `A-08` | 양중 러그 | SUS304 | 3 | 판재 | SUS304 t6 판재 80 × 60 | 70.0 × 50.0 | 290 | 3021 | 0.144 | O |
| `B-01` | 커버판 | SUS304 | 1 | 판재 | SUS304 t5 판재 Ø500 | 480.0 × 480.0 | 2570 | 174681 | 6.926 | O |
| `B-02` | 중앙 보강 허브 | SUS304 | 1 | 판재 | SUS304 t10 판재 Ø240 | 220.0 × 220.0 | 880 | 35186 | 2.790 | O |
| `B-03` | 허브 거싯 | SUS304 | 4 | 판재 | SUS304 t5 판재 90 × 70 | 76.0 × 58.0 | 229 | 2389 | 0.095 | O |
| `B-04` | 커버 노즐 | SUS316L | 3 | 관재 | SUS316L Ø12.7 × t1.65 위생튜브 + 페룰 | 12.7 × 12.7 | 69 | 57 | 0.027 | O |
| `B-07` | 스키머 조절봉 부싱 | SUS304 | 3 | 봉재 | SUS304 Ø20 환봉 L30 | 20.0 × 20.0 | 89 | 259 | 0.062 | O |
| `C-05` | 구동 램턴 / 어댑터 | SUS304 | 1 | 판재 | SUS304 t6 판재 + Ø180 × t5 관재 (HOLD) | 180.0 × 180.0 | 754 | 22619 | 1.076 | O |
| `C-06` | 보호 커버 | SUS304 | 1 | 전개 | SUS304 t1.5 판재 600 × 170 | 565.5 × 160.0 | 1451 | 90478 | 1.076 | O |
| `D-01` | 교반축 | SUS316L | 1 | 봉재 | SUS316L Ø28 환봉 L780 (가공 여유 포함) | 25.0 × 25.0 | 79 | 491 | 2.985 | O |
| `D-02` | 임펠러 (하부) | SUS316L | 1 | 판재 | 허브 Ø65 환봉 L70 + 날개 t3 판재 130 × 70 × 4 | 120.0 × 60.0 | 357 | 7197 | 1.805 | O |
| `D-03` | 임펠러 (상부) | SUS316L | 1 | 판재 | D-02 와 동일 — 같은 도면으로 2 개 제작 | 120.0 × 60.0 | 357 | 7197 | 1.805 | O |
| `D-06` | 스러스터 칼라 | SUS316L | 2 | 봉재 | SUS316L Ø55 환봉 L30 | 50.0 × 50.0 | 236 | 1473 | 0.295 | O |
| `E-01` | 배플판 | SUS316L | 4 | 판재 | SUS316L t3 판재 45 × 310 | 35.0 × 300.0 | 667 | 10497 | 0.252 | O |
| `E-02` | 스탠드오프 탭 | SUS316L | 12 | 판재 | SUS316L t3 판재 30 × 30 | 25.0 × 6.0 | 59 | 148 | 0.004 | O |
| `F-01` | 분산링 | SUS316L | 1 | 관재 | SUS316L Ø12 × t1.5 관재 L840 | 12.0 × 12.0 | 66 | 49 | 0.311 | O |
| `F-03` | 강하관 | SUS316L | 1 | 관재 | SUS316L Ø12 × t1.5 관재 L300 | 12.0 × 12.0 | 66 | 49 | 0.087 | O |
| `F-04` | 고정 브래킷 | SUS316L | 3 | 절곡 | SUS316L t3 판재 70 × 40 | 60.0 × 30.0 | 217 | 1664 | 0.040 | O |
| `G-01` | 스키머 링 (위어) | SUS316L | 1 | 전개 | SUS316L t2 판재 960 × 60 | 936.2 × 50.0 | 1972 | 46810 | 0.749 | O |
| `G-02` | 타공 바닥판 | SUS316L | 1 | 판재 | SUS316L t1.5 타공판 Ø310 (Ø2 · 개공률 30 %) | 300.0 × 300.0 | 4254 | 69030 | 0.594 | O |
| `G-04` | 인양 손잡이 | SUS316L | 1 | 봉재 | SUS316L Ø8 환봉 L340 | 8.0 × 8.0 | 25 | 50 | 0.137 | O |
| `H-01` | 기둥 | SUS304 | 4 | 관재 | SUS304 □40 × 40 × t2 각관 | 40.0 × 40.0 | 297 | 297 | 1.767 | O |
| `H-02` | 상·하부 둘레재 | SUS304 | 8 | 관재 | SUS304 □40 × 40 × t2 각관 | 40.0 × 40.0 | 297 | 297 | 1.202 | O |
| `H-03` | 상부 크로스레일 | SUS304 | 2 | 관재 | SUS304 □40 × 40 × t2 각관 | 40.0 × 40.0 | 297 | 297 | 1.107 | O |
| `H-04` | 중간 보강재 | SUS304 | 4 | 관재 | SUS304 □40 × 40 × t2 각관 | 40.0 × 40.0 | 297 | 297 | 1.202 | O |
| `H-06` | 베이스 플레이트 | SUS304 | 4 | 판재 | SUS304 t6 판재 110 × 110 | 100.0 × 100.0 | 572 | 9381 | 0.446 | O |
| `H-07` | 지지 브래킷 | SUS304 | 4 | 판재 | SUS304 t6 판재 90 × 70 | 90.0 × 70.0 | 383 | 5239 | 0.249 | O |

절단 길이 합계 약 **44.0 m** (수량 반영). 레이저 견적의 1 차 근거다.

## 3D 가 실물과 다른 곳

말거나 굽히는 부품은 **자르는 형상**과 **완성 형상**이 다르다. 자르는 것은 DXF 에, 완성은 STEP 에 있다.

| 부품 | 다른 점 |
|---|---|
| `A-01` | 3D 는 말고 난 원통이다. 노즐 구멍은 평판에서 뚫으므로 DXF 전개도에만 있다. |
| `A-02` | 3D 는 말고 난 원뿔이다. 자르는 것은 왼쪽 부채꼴이다. |
| `A-04` | 3D 는 대표 1 본이다. 나머지는 노즐표의 호칭으로 같은 방식. |
| `C-05` | HOLD 형상이다. 벤더 GA 가 나오기 전에는 발주하지 않는다. |
| `C-06` | 3D 는 말고 난 원통이다. 공구 없이 열리는 개방식이라 인터록은 걸지 않는다. |
| `D-02` | 3D 는 허브와 날개 4 매를 따로 담았다. 날개는 취부각 45° 로 세워 용접한다. |
| `D-03` | 3D 는 허브와 날개 4 매를 따로 담았다. 날개는 취부각 45° 로 세워 용접한다. |
| `F-01` | 3D 는 굽히기 전 곧은 관이다. 굽힘 후 PCD 와 평면도는 가공도의 치수로 잡는다. |
| `F-04` | 3D 는 굽히기 전 평판이다. |
| `G-01` | 3D 는 말고 난 링이다. |
| `G-02` | 구멍은 대표 구간만 담았다. 실제는 전면 타공이라 6 천 개를 솔리드로 담으면 열리지 않는다. |
| `G-04` | 3D 는 굽히기 전 곧은 봉이다. |

## 질량이 부품표와 다른 곳

CAD 질량은 구멍을 뺀 실형상이고, 부품표는 외형 기준 추정이거나 사 오는 부속(페룰 등)을 포함한다. 아래가 그 차이다.

| 부품 | CAD kg | 부품표 kg | 왜 |
|---|---|---|---|
| `A-03` | 0.124 | 0.344 | 부품표는 2" 페룰(0.22 kg)을 포함한다. CAD 는 만드는 관만 센다 |
| `A-04` | 0.034 | 0.290 | 부품표는 9 본 평균에 페룰 0.18 kg 을 더한 값. CAD 는 ½" 대표 관 1 본 |
| `A-08` | 0.144 | 0.167 | 부품표는 70 × 50 외형으로 셌다. CAD 는 모따기 18 과 Ø20 구멍을 뺀다 |
| `B-04` | 0.027 | 0.204 | 부품표는 페룰 포함 평균. CAD 는 관만 |
| `C-05` | 1.076 | 4.000 | 구동부 HOLD — 부품표 4.0 kg 은 어댑터 일체의 개략값이고 CAD 는 판 한 장이다. 벤더 GA 로 확정된다 |

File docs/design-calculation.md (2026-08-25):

# 태양광 셀 은(Ag) 회수 부선 설비 설계 계산서

> `PYTHONPATH=src python -m flotation_design` 로 자동 생성됨. 설계 기준은 `src/flotation_design/design_basis.py`, 근거 실험값은 `src/flotation_design/references.py` 참조.

## 0. 설계 근거

본 설계는 아래 두 실증 결과를 1차 근거로 삼는다. 모델 파라미터는 이 수치를 재현하도록 보정했고, `tests/test_references.py` 가 재현성을 검증한다.

| 출처 | 장치 | 조건 | 결과 |
|---|---|---|---|
| [1] Minerals Engineering 242 (2026) 110189 | 1 L 회분식 기계식 셀 | 7 wt%, Jg 0.20 cm/s, 150 g/t, 3 min, 수돗물, 자연 pH | Ag 회수율 97.6 %, 정광 24.0 wt% Ag, 농축비 32.2, 질량수율 2.92 % |
| [1] 동상 — 러퍼+클리너 개방회로 | 동상 | 클리너 1단 추가 | Ag 회수율 86.5 %, 정광 46.7 wt% Ag, 농축비 62.6 |
| [2] ChemRxiv 2026 (프리프린트) | 연속 1단 부선조 100x80 mm | Jf 2.0 / Jg 2.0 / Jw 0.81 cm/s, 기액 체류 1 min, 2 wt% | Ag 회수율 ~100 %, 정광 48.8 wt% Ag, 농축비 83, 질량수율 1.25 % |

> [!IMPORTANT]
> [2] 는 심사 전 프리프린트이며, 저자들이 해당 공정에 대해 호주 가출원(No. 2025902821, "Recovery of silver from photovoltaic cells")을 제출한 상태다. 상업화 전 실시권 검토가 필요하다.

## 1. 급광 사양

| 항목 | 값 | 근거 |
|---|---|---|
| 평균 / 최대 처리량 | 0.30 / 0.50 t/h (건조 고체) | 요구사항 |
| 원료 | 박리된 c-Si 셀 분획 (습식 로드밀 분쇄) | [1][2] |
| 급광 입도 P80 | 66 um | [2] |
| 설계 고체 농도 | 7 wt% | [1] 회분식 검증값. [2] 연속 실증은 2 wt%, 저자 주장 상한 30 wt% (PV 원료 미검증) |
| 고체 평균 비중 | 2.374 | 성분 조성 가중 |
| pH | 조정 없음 (자연 pH) | [1][2] 모두 무조정 운전 |
| 모듈 대비 셀 분획 비율 | 4.7 % | [2] |
| 환산 모듈 처리량 | 6.4 / 10.6 t/h | 상류 박리 설비가 감당해야 할 규모 |

| 성분 | 질량분율 (wt%) | 품위 (g/t) | 비중 | 속부선 | 지연부선 | 비부선 | k_fast | k_slow | 출처 |
|---|---|---|---|---|---|---|---|---|---|
| Si | 87.551 | 875,510 | 2.33 | 0 | 0 | 100 | 0.00 | 0.00 | 추정 |
| Ag_locked_gangue | 0.649 | 6,490 | 2.33 | 82 | 16 | 2 | 2.60 | 0.30 | 추정 |
| Al | 10.000 | 100,000 | 2.70 | 0 | 0 | 100 | 0.00 | 0.00 | 추정 |
| Ag | 0.590 | 5,900 | 10.49 | 82 | 16 | 2 | 2.60 | 0.30 | [2] assay |
| Pb | 0.096 | 960 | 11.34 | 15 | 10 | 75 | 1.50 | 0.25 | [1] Table 2 |
| Cu | 0.013 | 130 | 8.96 | 68 | 22 | 10 | 2.20 | 0.30 | [1] Table 2 |
| Other | 1.101 | 11,010 | 2.20 | 0 | 0 | 100 | 0.00 | 0.00 | 추정 |

속도상수는 **회분식 기준**이며, 실기 연속 셀에는 스케일업 계수 0.8 를 곱해 쓴다. Ag 의 비부선 분획 2.4 % 는 [1] 의 TIMA 해리도 분석(>90 % 해리 20 %, >60 % 해리 61 %)과 회분식 극한 회수율에 맞춘 값이다.

### 정광 품위의 물리적 상한

Ag 는 순수 입자가 아니라 Si 웨이퍼에 소결된 전극이다. 표면이 소수성이 되어 부상해도 **Si 코어를 함께 끌고 올라간다.** 부상 Ag 1 kg 당 동반 맥석 1.1 kg 으로 두면 정광 품위 상한은 1/(1+1.1) = **47.6 wt% Ag** 다. [2] 의 연속 정광이 48.8 wt%, [1] 의 러퍼+클리너 정광이 46.7 wt% 에서 멈춘 것이 이 상한으로 설명된다. 이 동반분은 **수분 동반과 달리 세척수로 제거되지 않는다** — 클리너를 아무리 더 붙여도 넘을 수 없는 벽이다.

## 2. 1안 (주설계) — 세척수 bias 연속 부선조 1단

| 항목 | 값 | 비고 |
|---|---|---|
| 기기 번호 / 역할 | FC-101 / 1단 연속 부선조 (세척수 bias) |  |
| **동체 내경** | **350 mm** | 단면적 0.0962 m2 |
| 라이저 높이 | 2.40 m | 기액 체류시간 1 min 유지 |
| 라이저 체적 | 0.231 m3 |  |
| 급광 flux Jf | 2.00 cm/s | [2] 실증값 유지 |
| 기체 flux Jg | 2.00 cm/s | [2] 실증값 유지 |
| 세척수 flux Jw | 0.81 cm/s | [2] 실증값 유지 |
| bias flux Jb | 0.25 cm/s | 양수 = 거품층 하향 순유량. 동반 맥석을 씻어내린다 |
| 경사판 | 70° / 간격 12 mm | 미광부 침강 강화 |
| 기포 크기 | 0.5~1.0 mm | [2] |
| 송풍기 | 0.37 kW, 6.9 m3/h @ 60 kPa |  |

스케일업은 **flux 상사**로 한다. 실증에서 확인된 급광·기체·세척수 flux 를 그대로 두고 단면적만 처리량에 비례해 키우면 기액 체류시간과 bias 조건이 보존된다. 체적을 키우는 것이 아니라 단면적을 키우는 것이 핵심이다.

| 운전점 | 고체 농도 | 급광 flux | 기액 체류 | 급광 | 공기 | 세척수 | 월류수 | 농도 여유 |
|---|---|---|---|---|---|---|---|---|
| 평균 0.30 t/h | 4 wt% | 2.00 cm/s | 1.00 min | 6.93 m3/h | 6.93 m3/h | 2.81 m3/h | 1.94 m3/h | 2.8 %p |
| 최대 0.50 t/h | 7 wt% | 2.00 cm/s | 1.00 min | 6.93 m3/h | 6.93 m3/h | 2.81 m3/h | 1.94 m3/h | 0.1 %p |

평균 처리량에서는 슬러리·공기·세척수 flux 를 실증값에 유지하고 급광 고체 농도를 낮춰 1분 체류시간을 보존한다. 세 flux를 함께 낮추면 체류시간이 늘어나므로 같은 성능으로 간주하지 않는다. 고체 농도를 올리면 같은 동체로 더 큰 처리량이 나오지만 — 7 wt% 에서 0.51 t/h, 15 wt% 에서 1.14 t/h, 30 wt% 에서 2.51 t/h. 다만 고농도 운전은 PV 원료로 미검증이므로 설계는 검증값에 둔다.

### 물질수지 — 최대 0.50 t/h

| 성분 | 급광 (kg/h) | 정광 (kg/h) | 미광 (kg/h) | 회수율 (%) | 정광 품위 (%) | 미광 품위 (g/t) |
|---|---|---|---|---|---|---|
| Si | 437.75 | 0.000 | 437.75 | 0.00 | 0.00 | 886,788 |
| Ag_locked_gangue | 3.25 | 3.235 | 0.01 | 99.70 | 50.88 | 20 |
| Al | 50.00 | 0.000 | 50.00 | 0.00 | 0.00 | 101,288 |
| Ag | 2.95 | 2.941 | 0.01 | 99.70 | 46.25 | 18 |
| Pb | 0.48 | 0.123 | 0.36 | 25.54 | 1.93 | 724 |
| Cu | 0.06 | 0.060 | 0.01 | 91.94 | 0.94 | 11 |
| Other | 5.51 | 0.000 | 5.51 | 0.00 | 0.00 | 11,152 |
| **합계** | **500.0** | **6.36** | **493.6** | **1.27** (질량수율) | **100.00** | — |

| 지표 | 값 |
|---|---|
| **Ag 회수율** | **99.7 %** |
| **Ag 정광 품위** | **46.3 wt%** |
| Ag 농축비 | 78.4 배 |
| Ag 미광 손실 | 0.009 kg/h (18 g/t) |
| 정광량 | 6.36 kg/h (급광의 1.27 %) |
| 후단 침출 물량 감소 | 79 배 |
| 물질수지 폐합 오차 | 1.4e-13 g/h |

### 물질수지 — 평균 0.30 t/h

| 성분 | 급광 (kg/h) | 정광 (kg/h) | 미광 (kg/h) | 회수율 (%) | 정광 품위 (%) | 미광 품위 (g/t) |
|---|---|---|---|---|---|---|
| Si | 262.65 | 0.000 | 262.65 | 0.00 | 0.00 | 886,788 |
| Ag_locked_gangue | 1.95 | 1.941 | 0.01 | 99.70 | 50.88 | 20 |
| Al | 30.00 | 0.000 | 30.00 | 0.00 | 0.00 | 101,288 |
| Ag | 1.77 | 1.765 | 0.01 | 99.70 | 46.25 | 18 |
| Pb | 0.29 | 0.074 | 0.21 | 25.54 | 1.93 | 724 |
| Cu | 0.04 | 0.036 | 0.00 | 91.94 | 0.94 | 11 |
| Other | 3.30 | 0.000 | 3.30 | 0.00 | 0.00 | 11,152 |
| **합계** | **300.0** | **3.82** | **296.2** | **1.27** (질량수율) | **100.00** | — |

| 지표 | 값 |
|---|---|
| **Ag 회수율** | **99.7 %** |
| **Ag 정광 품위** | **46.3 wt%** |
| Ag 농축비 | 78.4 배 |
| Ag 미광 손실 | 0.005 kg/h (18 g/t) |
| 정광량 | 3.82 kg/h (급광의 1.27 %) |
| 후단 침출 물량 감소 | 79 배 |
| 물질수지 폐합 오차 | 9.7e-14 g/h |

### 부대 설비

| 기기 | 역할 | 사양 |
|---|---|---|
| CT-1 | 포수제 + 촉진제 (3418A / AEROFLOAT 242) | 유효 0.577 m3 / 탱크 0.70 m3, Ø906 x 1087 mm, 교반 0.75 kW |
| TK-101 | 미광 농축 · 공정수 회수 | 월류 6.98 m3/h, 상승속도 1.2 m/h, Ø3.0 m |
| TK-102 | 정광 농축 · 여과 전단 | 월류 1.93 m3/h, 상승속도 1.2 m/h, Ø1.5 m |
| P-101 | 급광 펌프 | 1.5 kW |
| P-102 | 미광 펌프 | 0.75 kW |
| FL-101 | 정광 탈수 (제련·침출 급광) | 여과판 470 mm x 6 챔버, 면적 2.25 m2 |
| FL-102 | 미광 탈수 (공정수 회수 · 건식 적치) | 여과판 800 mm x 43 챔버, 면적 46.78 m2 |

| 항목 | FL-101 | FL-102 |
|---|---|---|
| 역할 | 정광 탈수 (제련·침출 급광) | 미광 탈수 (공정수 회수 · 건식 적치) |
| 급광 고체 (kg/h) | 6.36 | 493.64 |
| 급광 농도 (농축조 U/F) | 40 wt% | 45 wt% |
| 여과판 | 470 x 470 mm | 800 x 800 mm |
| 챔버 수 | 6 | 43 |
| **여과 면적 (m2)** | **2.25** | **46.78** |
| 챔버 총용적 (L) | 33.8 | 701.8 |
| 사이클 시간 (min) | 480 | 120 |
| 사이클/일 | 3.0 | 12.0 |
| 사이클당 건조 고체 (kg) | 50.9 | 987.3 |
| 챔버 충전율 | 96 % | 99 % |
| 케이크 함수율 | 18 wt% | 22 wt% |
| **케이크 생산량 (kg/h)** | **7.8** | **632.9** |
| 여액 (m3/h) | 0.008 | 0.464 |
| 급광 펌프 (kW) | 0.75 | 2.20 |
| 규격 결정 기준 | 상용 최소 기종 | 챔버 용적 |

**설치 전력 6.52 kW**, 공정수 회수 9.38 m3/h. 농축조 월류 블리드 0.89 m3/h와 케이크 잔류수를 합한 신수 보충량은 **1.03 m3/h** 다.

이 가운데 필터프레스 여액 0.472 m3/h 는 공정수 탱크가 아니라 **CT-1 조건조 (FC-101 급광)** 으로 되돌린다. 여포를 빠져나온 미립자가 남아 있어 공정수로 희석하면 그 안의 Ag 를 그대로 잃기 때문이다.

## 3. 2안 (대안) — 기계식 러퍼 · 스캐빈저 · 클리너 3단

기존 부선 설비를 그대로 쓰거나 범용 장비로 구성해야 할 때의 대안이다. 러퍼 정광은 클리너로, 러퍼 미광은 스캐빈저로 간다. 스캐빈저 정광과 클리너 미광은 러퍼 급광으로 되돌린다. 급기는 **중공축**으로 넣어 로터가 직접 분산시킨다 (별도 스파저 없음).

| 항목 | FC-201 (1기) | FC-202 (1기) | FC-203 (1기) |
|---|---|---|---|
| 역할 | 러퍼 (Rougher) | 스캐빈저 (Scavenger) | 클리너 (Cleaner) |
| 셀당 내부 치수 (mm) | Ø1000 x 1300(H) | Ø1000 x 1300(H) | Ø400 x 650(H) |
| 거품층 (mm) | 75 | 50 | 150 |
| 셀당 유효 슬러리 체적 (m3) | 0.778 | 0.794 | 0.049 |
| 로터 지름 (mm) | 350 | 350 | 140 |
| 회전수 (rpm) | 290 | 290 | 610 |
| 주속 (m/s) | 5.31 | 5.31 | 4.47 |
| 셀당 모터 (kW) | 4.00 | 4.00 | 0.37 |
| 설계 Jg (cm/s) | 0.30 | 0.34 | 0.20 |
| 셀당 급기량 (m3/h) | 8.5 | 9.6 | 0.9 |
| 체류시간 (min, 최대유량) | 6.53 | 7.09 | 6.92 |
| **중공축 보어 (mm)** | **Ø20** | **Ø20** | **Ø10** |
| 중공축 외경 (mm) | Ø60 | Ø60 | Ø50 |
| 축 길이 (m) | 1.85 | 1.85 | 1.20 |
| 축 내부 공기 유속 (m/s) | 11.2 | 12.5 | 5.6 |
| 전달 토크 (N·m) | 263 | 263 | 12 |
| 비틀림 전단응력 (MPa) | 6.3 / 40 | 6.3 / 40 | 0.5 / 40 |
| 외경 결정 기준 | 로터동역학 | 로터동역학 | 로터동역학 |
| 급기 압력손실 (kPa) | 6.8 | 7.0 | 6.1 |
| 분산구 | 8 x Ø5 mm | 8 x Ø5 mm | 8 x Ø3 mm |
| 1차 임계회전수 / 운전비 | 480 rpm / 1.65x | 480 rpm / 1.65x | 1161 rpm / 1.90x |
| 예비 정적 처짐 (mm) | 4.72 | 4.72 | 0.89 |

**러퍼·스캐빈저 표준화.** 첨부 문헌에는 스캐빈저 단독 시험이나 8분 체류시간의 근거가 없으므로, FC-202를 임의로 대형화하지 않고 FC-201과 같은 동체·로터·구동부로 통일했다. FC-202는 거품층을 더 얕게 운전하므로 같은 동체에서도 유효 체적과 실제 체류시간이 조금 더 크다. locked-cycle 시험에서 추가 체류시간의 유효성이 확인될 때만 예비 공간에 2차 스캐빈저를 직렬 증설한다.

**중공축 급기.** 축 상단 로터리 조인트로 공기를 넣어 축 내부 보어를 지나 로터 허브의 분산구 8개로 내보낸다. 로터가 직접 기포를 부수므로 스파저 방식보다 기포가 잘고 균일하다. 축 외경은 단순 L/D가 아니라 로터 집중질량을 포함한 외팔보 예비 모델로 1차 임계회전수와 정적 처짐을 검산했다. 실제 제작 전에는 확정 베어링 스팬·불평형 하중으로 로터동역학을 다시 확인해야 한다. 송풍기 압력은 펄프 수두에 축 보어·로터리 조인트·허브 분산구 손실을 더해 선정했다.

송풍기 공용 1대 0.55 kW (28 m3/h @ 25 kPa), 미광/정광 농축조 TK-201/TK-202 Ø2.5/1.0 m. **설치 전력 15.07 kW.**

### 탈수 라인

| 항목 | FL-201 | FL-202 |
|---|---|---|
| 역할 | 정광 탈수 (제련·침출 급광) | 미광 탈수 (공정수 회수 · 건식 적치) |
| 급광 고체 (kg/h) | 6.08 | 493.92 |
| 급광 농도 (농축조 U/F) | 40 wt% | 45 wt% |
| 여과판 | 470 x 470 mm | 800 x 800 mm |
| 챔버 수 | 6 | 43 |
| **여과 면적 (m2)** | **2.25** | **46.78** |
| 챔버 총용적 (L) | 33.8 | 701.8 |
| 사이클 시간 (min) | 480 | 120 |
| 사이클/일 | 3.0 | 12.0 |
| 사이클당 건조 고체 (kg) | 48.6 | 987.8 |
| 챔버 충전율 | 92 % | 99 % |
| 케이크 함수율 | 18 wt% | 22 wt% |
| **케이크 생산량 (kg/h)** | **7.4** | **633.2** |
| 여액 (m3/h) | 0.008 | 0.464 |
| 급광 펌프 (kW) | 0.75 | 2.20 |
| 규격 결정 기준 | 상용 최소 기종 | 챔버 용적 |

여액 0.472 m3/h 는 공정수 탱크를 거치지 않고 **FC-201 러퍼 급광** 으로 직접 되돌린다 — 여포를 빠져나온 미립자에 Ag 가 남아 있어 회로 첫 단에서 한 번 더 부선 기회를 준다. 두 농축조 월류수와 합친 공정수 회수량은 6.31 m3/h, 블리드 0.58 m3/h와 케이크 잔류수를 보충하는 신수는 **0.72 m3/h** 다.

### 물질수지 — 최대 0.50 t/h

| 단 | 체류시간 (min) | 급광 (kg/h) | 정광 (kg/h) | mass pull | Ag 회수율 |
|---|---|---|---|---|---|
| FC-201 | 6.53 | 521.1 | 17.53 | 3.36 % | 84.1 % |
| FC-202 | 7.09 | 503.6 | 9.66 | 1.92 % | 65.5 % |
| FC-203 | 6.92 | 17.5 | 6.08 | 34.67 % | 88.2 % |

| 지표 | 값 |
|---|---|
| **Ag 회로 회수율** | **93.1 %** |
| **Ag 정광 품위** | **45.2 wt%** |
| Ag 농축비 | 76.6 배 |
| Ag 미광 손실 | 0.203 kg/h (411 g/t) |
| 정광량 | 6.08 kg/h (1.22 %) |
| 순환부하 | 4.2 % |
| 회로 희석·세척수 요구량 (여액 제외) | 5.98 m3/h |
| 필터 여액 러퍼 직송 | 0.472 m3/h |
| 물질수지 폐합 오차 | 8.7e-08 g/h |

### 물질수지 — 평균 0.30 t/h

| 단 | 체류시간 (min) | 급광 (kg/h) | 정광 (kg/h) | mass pull | Ag 회수율 |
|---|---|---|---|---|---|
| FC-201 | 10.90 | 312.3 | 10.46 | 3.35 % | 88.8 % |
| FC-202 | 11.83 | 301.9 | 5.63 | 1.86 % | 67.0 % |
| FC-203 | 11.55 | 10.5 | 3.75 | 35.84 % | 92.0 % |

| 지표 | 값 |
|---|---|
| **Ag 회로 회수율** | **95.7 %** |
| **Ag 정광 품위** | **45.2 wt%** |
| Ag 농축비 | 76.6 배 |
| Ag 미광 손실 | 0.076 kg/h (258 g/t) |
| 정광량 | 3.75 kg/h (1.25 %) |
| 순환부하 | 4.1 % |
| 회로 희석·세척수 요구량 (여액 제외) | 3.68 m3/h |
| 필터 여액 러퍼 직송 | 0.283 m3/h |
| 물질수지 폐합 오차 | 5.7e-08 g/h |

#### 확정 치수 검증

| 셀 | 목표 체류시간 | 필요 유효 체적 | 확정 유효 체적 | 실제 체류시간 | 판정 |
|---|---|---|---|---|---|
| FC-201 | 6.0 min | 0.714 m3 | 0.778 m3 | 6.53 min | OK |
| FC-202 | 6.0 min | 0.672 m3 | 0.794 m3 | 7.09 min | OK |
| FC-203 | 6.0 min | 0.042 m3 | 0.049 m3 | 6.92 min | OK |

**스캐빈저 효과.** 같은 러퍼·클리너 회로에서 스캐빈저만 빼면 Ag 회수율은 84.2 %이고, 3단 폐회로는 93.1 %다 (+8.9 %p). 미광 Ag도 940 → 411 g/t로 낮아진다. 스캐빈저 포수제 추가량은 실증 근거가 없어 기본계산에는 증량을 적용하지 않았다.

## 4. 두 안 비교

| 지표 | 1안 연속 부선조 | 2안 기계식 3단 | 판정 |
|---|---|---|---|
| Ag 회수율 | **99.7 %** | 93.1 % | 1안 +6.6 %p |
| Ag 정광 품위 | 46.3 wt% | 45.2 wt% | 동등 (복합입자 상한) |
| Ag 미광 손실 | 18 g/t | 411 g/t | 1안 압도적 |
| 부선기 대수 | 1기 | 3기 | 1안 |
| 설치 전력 | **6.52 kW** | 15.07 kW | 1안 57 % 절감 |
| 부선기 설치 면적 | Ø350 mm x 3.6 m(H) | 2.2 x 1.3 m | 1안 |
| 체류시간 | 1 min (기액) | 6.5 + 7.1 + 6.9 min | 1안 |
| 순환류 | 없음 | 4.2 % (스캐빈저 정광 + 클리너 미광) | 1안 |
| 기술 성숙도 | TRL 5 (연속 실증 90 min) | 범용 장비, 회분식만 실증 | 2안이 조달 유리 |
| 지식재산 | 가출원 대상 — 실시권 검토 필요 | 제약 없음 | 2안이 유리 |

**권고 — 1안.** 회수율이 6.6 %p 높고 전력은 57 % 낮으며 장치가 1기다. 정광 품위는 두 안이 같은데, 이는 품위가 장치가 아니라 복합입자 동반이라는 **원료 자체의 성질**로 결정되기 때문이다. 다만 1안은 특정 장치 형식에 의존하고 특허 가출원 대상이므로, 조달·실시권 리스크가 크다면 2안이 현실적 차선이다.

## 5. 약제 계통

**pH 조정제·황화제·억제제를 쓰지 않는다.** 디티오포스핀산계 포수제가 금속 Ag 표면에 직접 선택 흡착하기 때문이다 ([1] ToF-SIMS: Ag 위 신호가 주변 대비 약 100배). 이전 설계의 소다회·Na2S·규산소다 계통이 통째로 사라지면서 H2S 위험과 pH·ORP 제어 루프도 함께 없어진다.

### 평균 0.30 t/h (1안 기준, 물 6.80 m3/h)

| 약제 | 역할 | 투입량 | 환산 (g/t) | 유효성분 (kg/h) | 조제농도 | 펌프 유량 (L/h) | 펌프 선정 (L/h) | 투입 지점 |
|---|---|---|---|---|---|---|---|---|
| AEROPHINE 3418A (sodium diisobutyl dithiophosphinate) | 포수제 | 300 g/t | 300 | 0.090 | 10% | 0.88 | 1.8 | CT-1 조건조 |
| AEROFLOAT 242 (dithiophosphate + thiourea 촉진제) | 촉진제 | 300 g/t | 300 | 0.090 | 10% | 0.88 | 1.8 | CT-1 조건조 |
| MIBC | 기포제 | 30 ppm(물) | 680 | 0.204 | 원액 | 0.25 | 1.0 | 급광박스 |

### 최대 0.50 t/h (1안 기준, 물 6.72 m3/h)

| 약제 | 역할 | 투입량 | 환산 (g/t) | 유효성분 (kg/h) | 조제농도 | 펌프 유량 (L/h) | 펌프 선정 (L/h) | 투입 지점 |
|---|---|---|---|---|---|---|---|---|
| AEROPHINE 3418A (sodium diisobutyl dithiophosphinate) | 포수제 | 300 g/t | 300 | 0.150 | 10% | 1.47 | 2.9 | CT-1 조건조 |
| AEROFLOAT 242 (dithiophosphate + thiourea 촉진제) | 촉진제 | 300 g/t | 300 | 0.150 | 10% | 1.47 | 2.9 | CT-1 조건조 |
| MIBC | 기포제 | 30 ppm(물) | 403 | 0.201 | 원액 | 0.25 | 1.0 | 급광박스 |

**관리 포인트**

- **AEROPHINE 3418A (sodium diisobutyl dithiophosphinate)** — 금속 Ag 표면에 직접 선택 흡착한다 (ToF-SIMS: Ag 위 신호가 주변 대비 약 100배). **황화 전처리가 필요 없다.**
- **AEROFLOAT 242 (dithiophosphate + thiourea 촉진제)** — 3418A 와 병용해 Ag 포집을 보강한다. 건조 원료 기준 최적은 150 g/t 였으나 습식 분쇄물에는 300 g/t 가 필요했다.
- **MIBC** — 연속 운전에서 거품 안정화를 위해 별도 기포제로 투입. 물 기준 30 ppm 이므로 고체 농도를 올리면 t 당 소요량이 줄어든다. 수용해도가 약 17 g/L 라 희석하면 정량펌프 유량이 20 L/h 까지 커지므로 **원액 투입**하고, 소용량 정량펌프에 검량통(calibration column)을 단다.

## 6. 모델 검증 — 문헌 재현

| 항목 | 문헌값 | 모델값 | 차이 |
|---|---|---|---|
| [1] 회분식 Ag 회수율 @ 1 min | 80.0 % | 80.0 % | -0.1 % |
| [1] 회분식 Ag 회수율 @ 3 min | 90.0 % | 91.2 % | +1.4 % |
| [1] 회분식 Ag 극한 회수율 | 97.6 % | 97.6 % | +0.0 % |
| [1] 회분식 Cu 회수율 @ 3 min | 81.4 % | 81.0 % | -0.5 % |
| [1] 회분식 Pb 회수율 @ 3 min | 20.9 % | 20.1 % | -3.8 % |
| [2] 연속 Ag 회수율 | 99.7 % | 99.7 % | +0.0 % |
| [2] 연속 질량수율 | 1.25 % | 1.27 % | +1.7 % |
| [2] 연속 정광 Ag 품위 | 48.8 wt% | 46.3 wt% | -5.2 % |
| [1] 러퍼+클리너 정광 Ag 품위 | 46.7 wt% | 45.2 wt% | -3.2 % |

연속 부선조는 **반응속도 모델을 쓰지 않는다.** 완전혼합조가 아니라 스파저·유동층·경사판·세척수 bias 로 구성된 흐름 장치라, 기액 체류시간 1분을 CSTR 식에 대입하면 Ag 회수율이 63 % 로 나와 실측(~100 %)과 전혀 맞지 않는다. flux 상사로 스케일업하면 수력학적 조건이 보존되므로 실증 측정값을 그대로 이월하는 것이 옳다.

## 7. 수치해석 — 수력학 검산과 기동 과도응답

### 7.1 기포-입자 수력학 검산

설계가 쓰는 속도상수는 문헌 회분식 곡선에 맞춘 경험값이다. 제1원리로 그 값이 물리적으로 성립하는지 검산한다 — 기포 종말속도(Schiller-Naumann 항력 반복해) → 기포 Reynolds 수 → Yoon-Luttrell 충돌 효율 Ec → 포집 속도상수 k = (3/2)·Ea·Ec·Jg/db. 여기서 부착 효율 Ea 만 미지수이므로, 속부선 분획의 설계 속도상수 (회분식 2.60 × 스케일업 계수 0.8 = 2.08 1/min) 를 재현하는 Ea 를 역산한다.

| 셀 | 기포 상승 단일/군 (cm/s) | Re | 충돌 효율 Ec | k 이상값 (1/min) | k 설계값 (1/min) | 역산 Ea | 펄프 통과 |
|---|---|---|---|---|---|---|---|
| FC-201 | 9.1 / 6.5 | 72 | 4.98 % | 16.8 | 2.08 | **0.124** | 18 s |
| FC-202 | 9.1 / 6.5 | 72 | 4.98 % | 19.0 | 2.08 | **0.109** | 18 s |
| FC-203 | 9.1 / 7.0 | 72 | 4.98 % | 11.2 | 2.08 | **0.186** | 6 s |

역산된 부착 효율 Ea 0.11~0.19 는 수십 µm 급 입자의 문헌 범위(0.1~0.3)에 들어간다 — **설계 속도상수는 물리적으로 정합적이다.** 입자 침강속도는 3.2 mm/s (P80 66 µm) 로 순환 유속 수십 cm/s 대비 무시할 만해, 셀 바닥 모래화(sanding) 위험은 낮다.

### 7.2 기동 과도응답

빈 셀에서 급광을 넣기 시작한 순간부터 회로가 정상상태에 도달할 때까지를 성분별 셀 재고에 대한 CSTR 연립 ODE 로 적분했다 (RK4, Δt 0.02 min). 유효 속도상수는 정상상태 해에서 역산했으므로, 적분이 수렴하면 정상상태 물질수지와 **정확히 같은 값**에 도달해야 한다 — 이것이 곧 두 계산의 교차 검증이다.

| 지표 | 값 |
|---|---|
| 회수율 95 % 도달 (t95) | **7.0 min** |
| 회수율 99 % 도달 (t99) | 12.0 min |
| 120 min 시점 Ag 회수율 (ODE) | 93.12 % |
| 정상상태 해 (수렴 계산) | 93.12 % |
| 두 계산의 차이 | 2.5e-09 %p |
| 120 min 시점 순환부하 (ODE) | 4.22 % |

기동 후 **약 7분(단별 체류시간 합의 약 0.3배)** 이면 성능 보증값 측정을 시작할 수 있다. 순환류(스캐빈저 정광·클리너 미광)가 안정되는 데 걸리는 시간도 같은 규모다. 시운전 계획의 안정화 대기 시간 산정 근거가 된다.

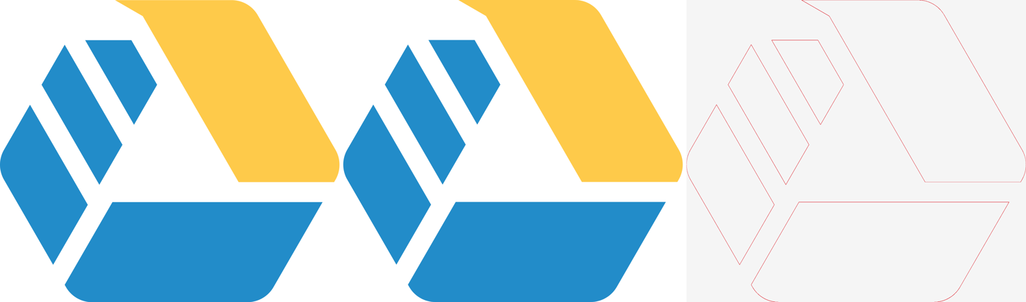
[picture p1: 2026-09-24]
docs/brand/extraction-check.png

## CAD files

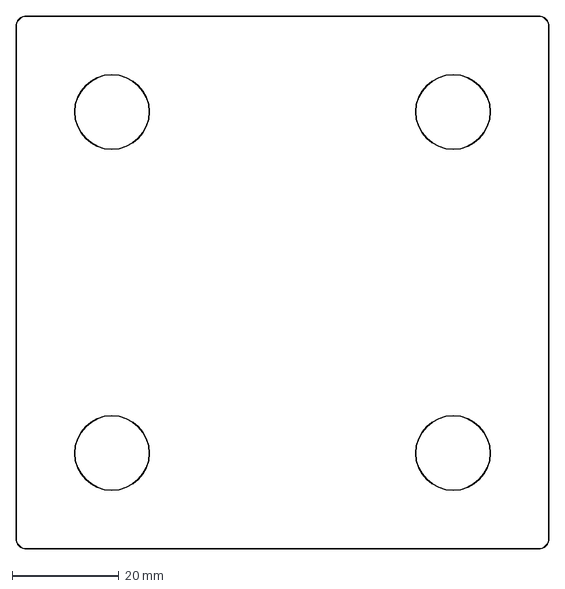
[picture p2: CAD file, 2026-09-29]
docs/cad/dxf/cut/MP50-C-H-06-CUT.dxf
100.0 x 100.0 mm

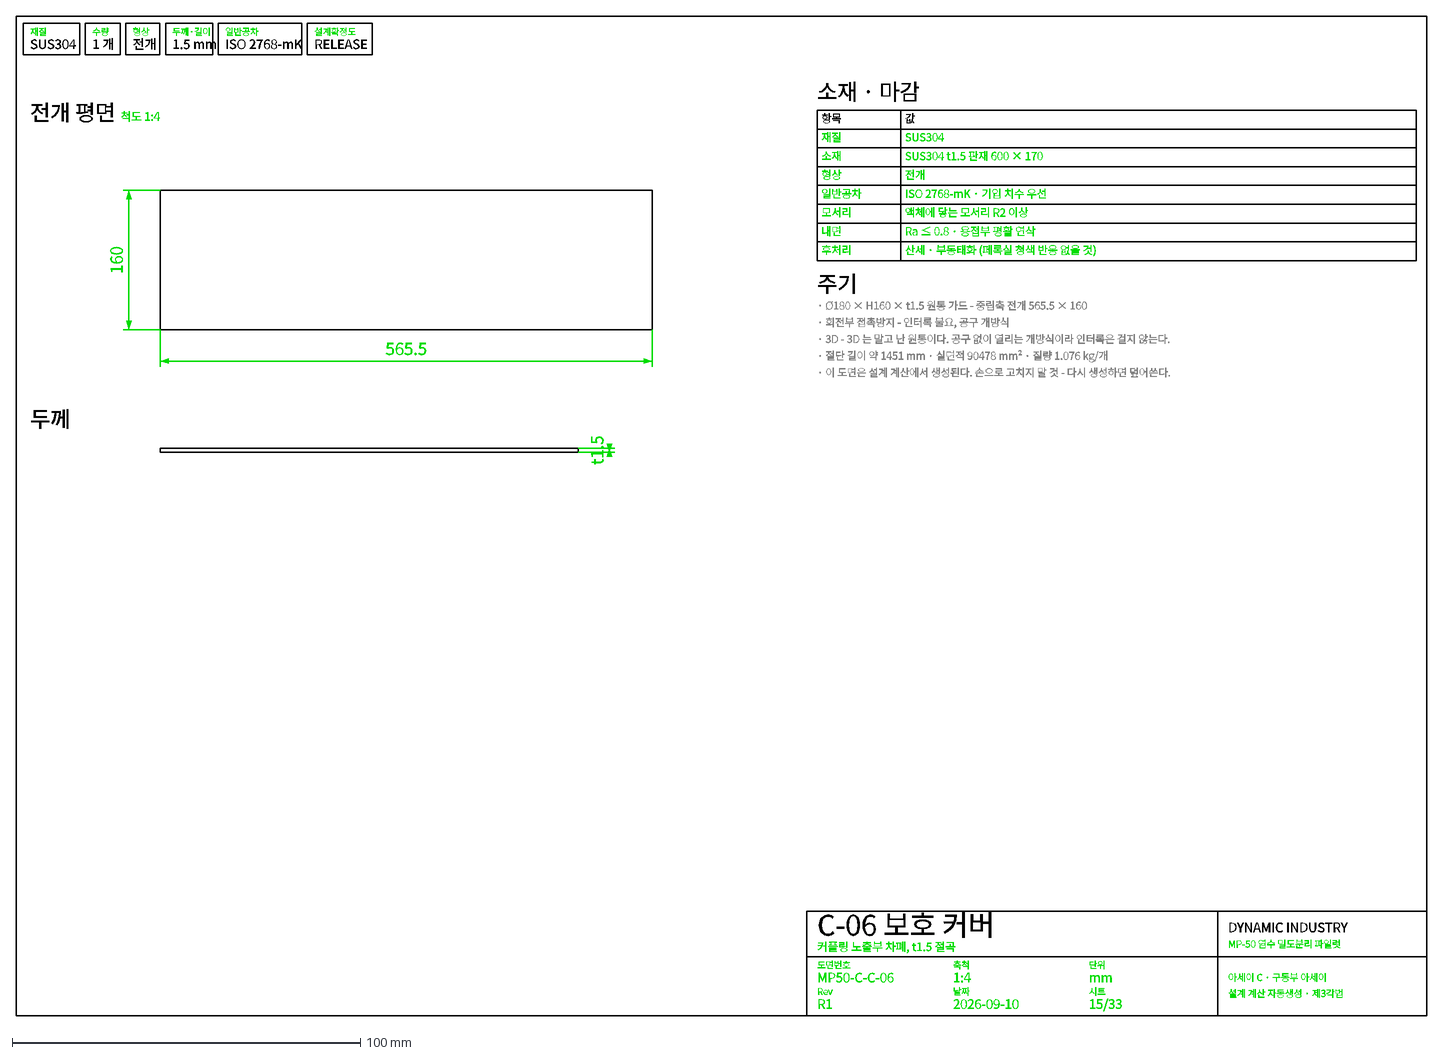
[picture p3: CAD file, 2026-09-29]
docs/cad/dxf/dwg/MP50-C-C-06.dxf
재질
SUS304
수량
1 개
형상
전개
두께·길이
1.5 mm
일반공차
ISO 2768-mK
설계확정도
RELEASE
C-06 보호 커버
커플링 노출부 차폐, t1.5 절곡
도면번호
MP50-C-C-06
축척
1:4
단위
mm
Rev
R1
날짜
2026-09-10
시트
15/33
DYNAMIC INDUSTRY
MP-50 염수 밀도분리 파일럿
아세이 C · 구동부 아세이
설계 계산 자동생성 · 제3각법
전개 평면
척도 1:4
565.5
160
두께
t1.5
소재 · 마감
항목
값
소재
SUS304 t1.5 판재 600 × 170
ISO 2768-mK · 기입 치수 우선
모서리
액체에 닿는 모서리 R2 이상
내면
Ra ≤ 0.8 · 용접부 평활 연삭
후처리
산세 · 부동태화 (페록실 청색 반응 없을 것)
주기
· Ø180 × H160 × t1.5 원통 가드 - 중립축 전개 565.5 × 160
· 회전부 접촉방지 - 인터록 불요, 공구 개방식
· 3D - 3D 는 말고 난 원통이다. 공구 없이 열리는 개방식이라 인터록은 걸지 않는다.
· 절단 길이 약 1451 mm · 실면적 90478 mm² · 질량 1.076 kg/개
· 이 도면은 설계 계산에서 생성된다. 손으로 고치지 말 것 - 다시 생성하면 덮어쓴다.

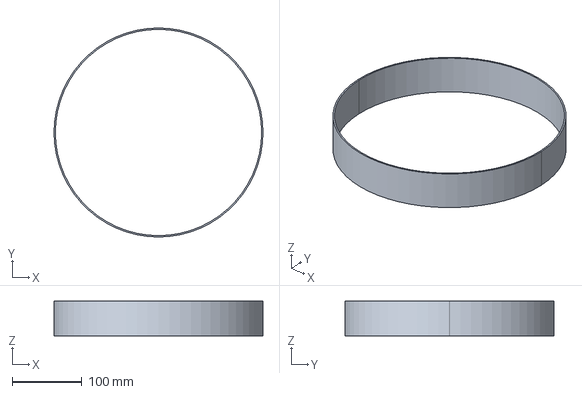
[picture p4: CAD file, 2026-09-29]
docs/cad/step/MP50-G-01.stp
300.0 x 300.0 x 50.0 mm

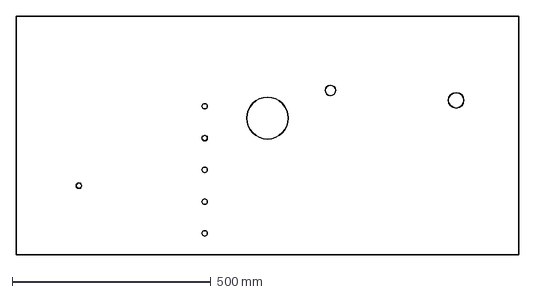
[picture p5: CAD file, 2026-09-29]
docs/cad/dxf/cut/MP50-C-A-01-CUT.dxf
1266.1 x 600.0 mm

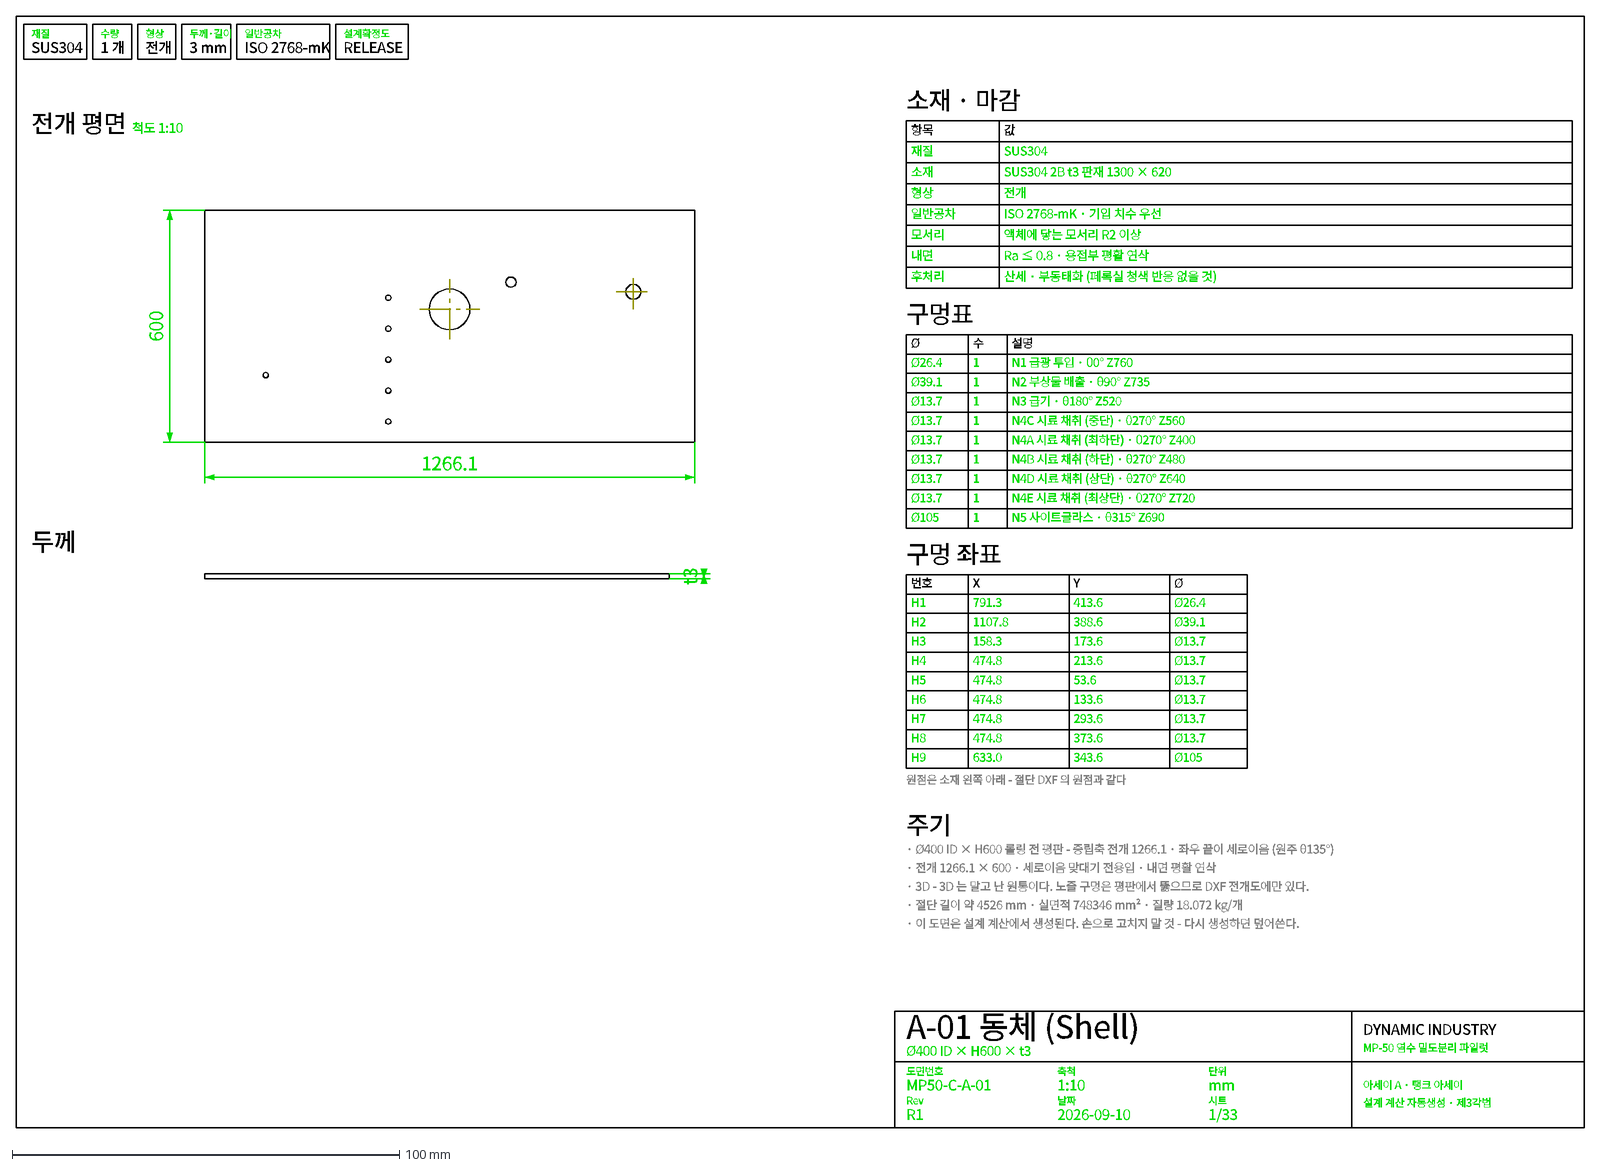
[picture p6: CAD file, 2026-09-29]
docs/cad/dxf/dwg/MP50-C-A-01.dxf
재질
SUS304
수량
1 개
형상
전개
두께·길이
3 mm
일반공차
ISO 2768-mK
설계확정도
RELEASE
A-01 동체 (Shell)
Ø400 ID × H600 × t3
도면번호
MP50-C-A-01
축척
1:10
단위
mm
Rev
R1
날짜
2026-09-10
시트
1/33
DYNAMIC INDUSTRY
MP-50 염수 밀도분리 파일럿
아세이 A · 탱크 아세이
설계 계산 자동생성 · 제3각법
전개 평면
척도 1:10
1266.1
600
두께
t3
소재 · 마감
항목
값
소재
SUS304 2B t3 판재 1300 × 620
ISO 2768-mK · 기입 치수 우선
모서리
액체에 닿는 모서리 R2 이상
내면
Ra ≤ 0.8 · 용접부 평활 연삭
후처리
산세 · 부동태화 (페록실 청색 반응 없을 것)
구멍표
Ø
수
설명
Ø26.4
1
N1 급광 투입 · θ0° Z760
Ø39.1
N2 부상물 배출 · θ90° Z735
Ø13.7
N3 급기 · θ180° Z520
N4C 시료 채취 (중단) · θ270° Z560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

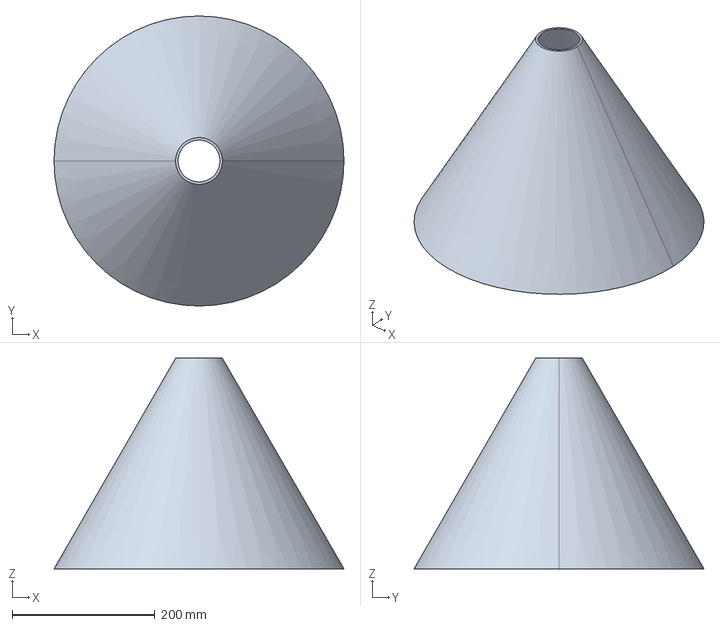
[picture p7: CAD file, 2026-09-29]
docs/cad/step/MP50-A-02.stp
406.0 x 406.0 x 294.9 mm

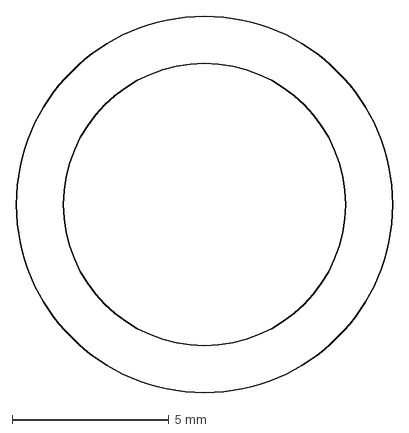
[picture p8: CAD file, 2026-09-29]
docs/cad/dxf/cut/MP50-C-F-01-CUT.dxf
12.0 x 12.0 mm

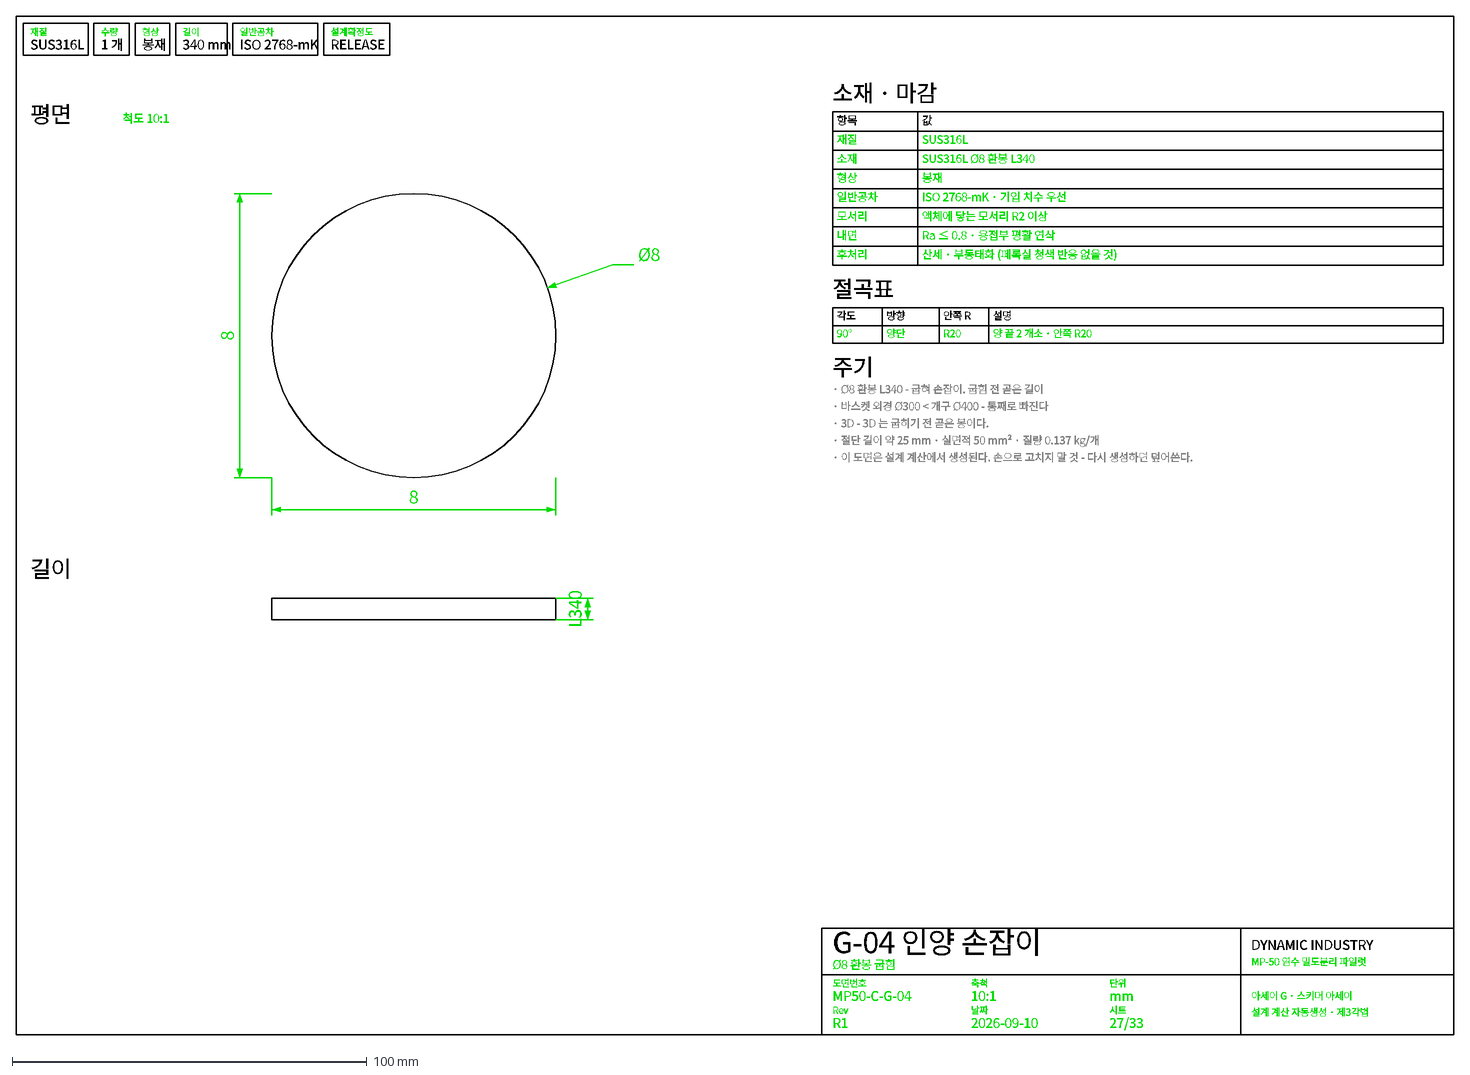
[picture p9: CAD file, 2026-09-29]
docs/cad/dxf/dwg/MP50-C-G-04.dxf
재질
SUS316L
수량
1 개
형상
봉재
길이
340 mm
일반공차
ISO 2768-mK
설계확정도
RELEASE
G-04 인양 손잡이
Ø8 환봉 굽힘
도면번호
MP50-C-G-04
축척
10:1
단위
mm
Rev
R1
날짜
2026-09-10
시트
27/33
DYNAMIC INDUSTRY
MP-50 염수 밀도분리 파일럿
아세이 G · 스키머 아세이
설계 계산 자동생성 · 제3각법
평면
척도 10:1
8
Ø8
L340
소재 · 마감
항목
값
소재
SUS316L Ø8 환봉 L340
ISO 2768-mK · 기입 치수 우선
모서리
액체에 닿는 모서리 R2 이상
내면
Ra ≤ 0.8 · 용접부 평활 연삭
후처리
산세 · 부동태화 (페록실 청색 반응 없을 것)
절곡표
각도
방향
안쪽 R
설명
90°
양단
R20
양 끝 2 개소 · 안쪽 R20
주기
· Ø8 환봉 L340 - 굽혀 손잡이. 굽힘 전 곧은 길이
· 바스켓 외경 Ø300 < 개구 Ø400 - 통째로 빠진다
· 3D - 3D 는 굽히기 전 곧은 봉이다.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

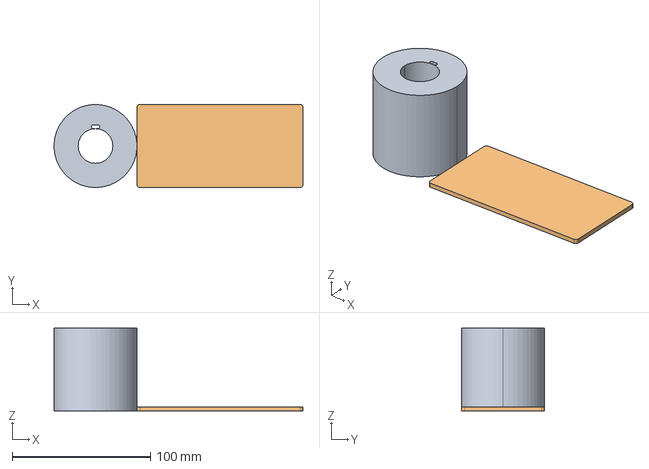
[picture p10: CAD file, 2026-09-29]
docs/cad/step/MP50-D-02.stp
180.0 x 60.0 x 60.0 mm

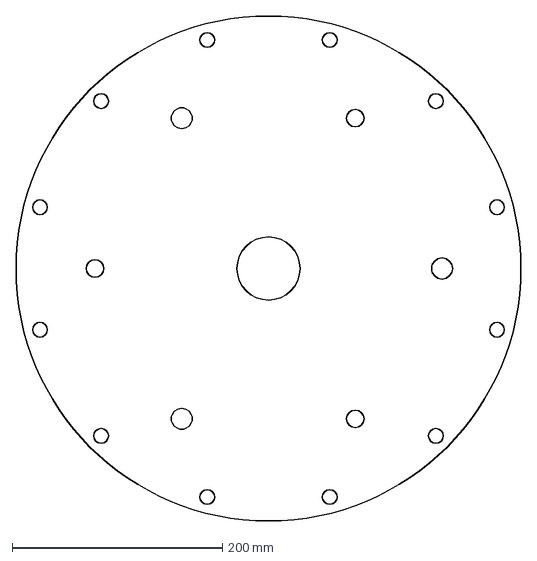
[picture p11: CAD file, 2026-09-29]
docs/cad/dxf/cut/MP50-C-B-01-CUT.dxf
480.0 x 480.0 mm

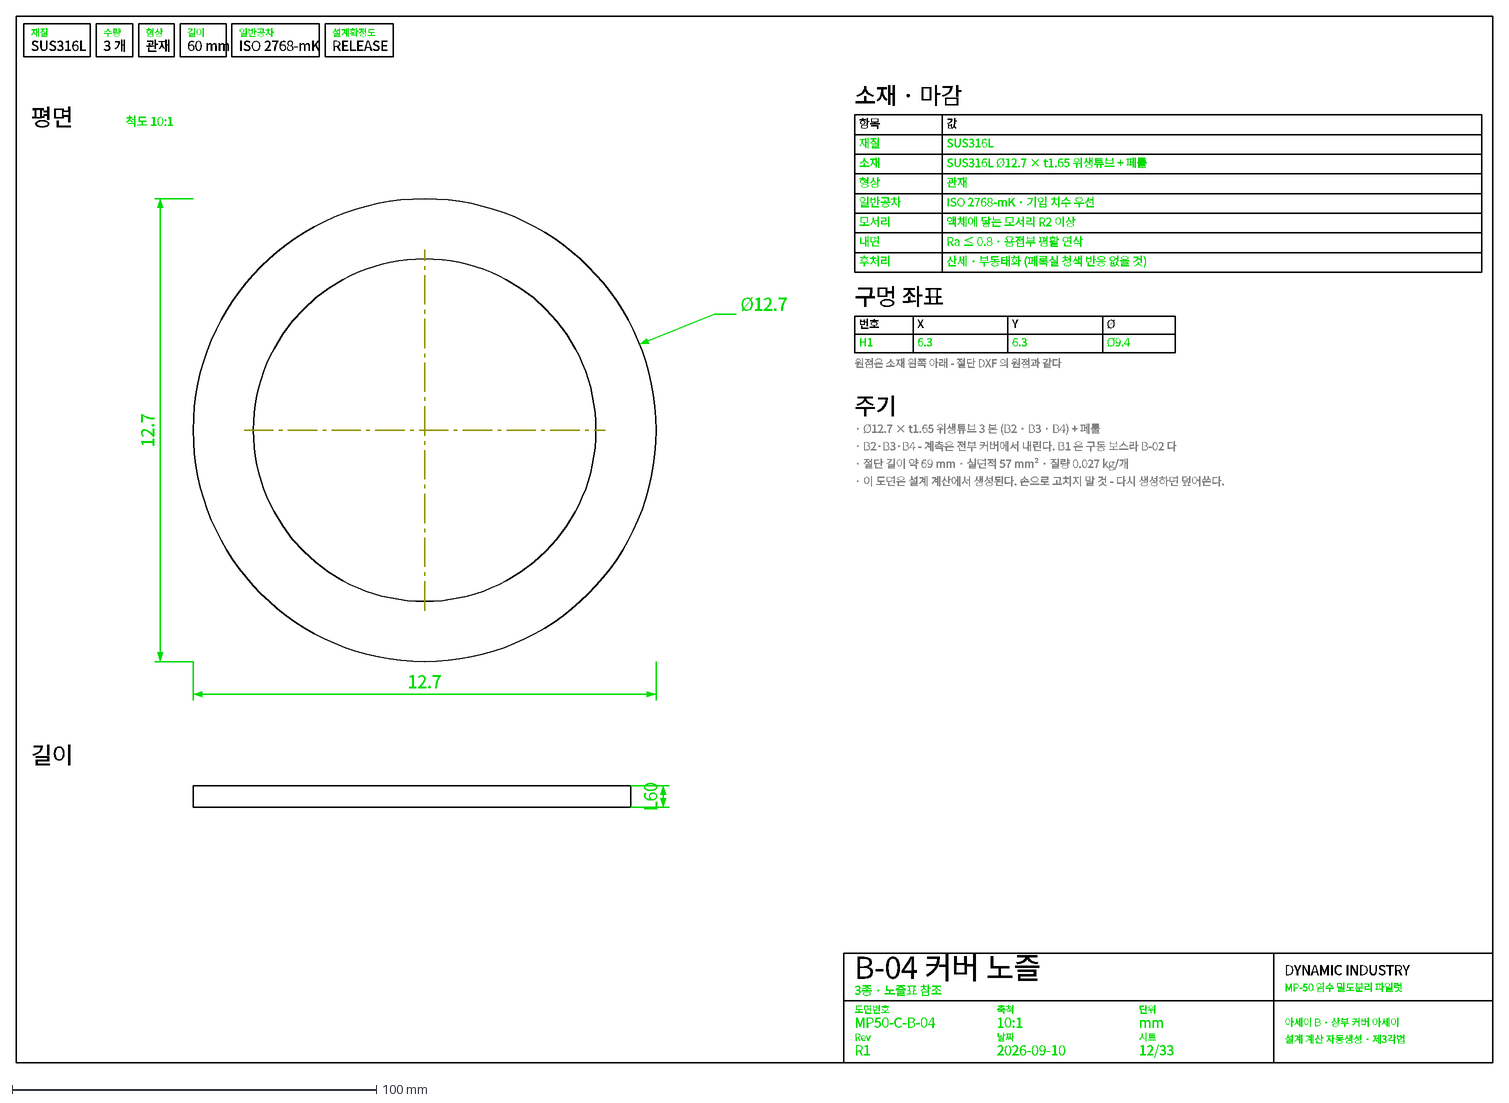
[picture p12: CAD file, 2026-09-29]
docs/cad/dxf/dwg/MP50-C-B-04.dxf
재질
SUS316L
수량
3 개
형상
관재
길이
60 mm
일반공차
ISO 2768-mK
설계확정도
RELEASE
B-04 커버 노즐
3종 · 노즐표 참조
도면번호
MP50-C-B-04
축척
10:1
단위
mm
Rev
R1
날짜
2026-09-10
시트
12/33
DYNAMIC INDUSTRY
MP-50 염수 밀도분리 파일럿
아세이 B · 상부 커버 아세이
설계 계산 자동생성 · 제3각법
평면
척도 10:1
12.7
Ø12.7
L60
소재 · 마감
항목
값
소재
SUS316L Ø12.7 × t1.65 위생튜브 + 페룰
ISO 2768-mK · 기입 치수 우선
모서리
액체에 닿는 모서리 R2 이상
내면
Ra ≤ 0.8 · 용접부 평활 연삭
후처리
산세 · 부동태화 (페록실 청색 반응 없을 것)
구멍 좌표
번호
X
Y
Ø
H1
6.3
Ø9.4
원점은 소재 왼쪽 아래 - 절단 DXF 의 원점과 같다
주기
· Ø12.7 × t1.65 위생튜브 3 본 (B2 · B3 · B4) + 페룰
· B2·B3·B4 - 계측은 전부 커버에서 내린다. B1 은 구동 보스라 B-02 다
· 절단 길이 약 69 mm · 실면적 57 mm² · 질량 0.027 kg/개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

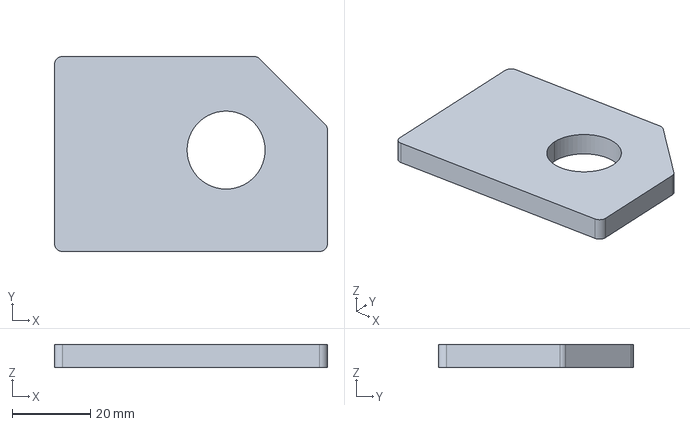
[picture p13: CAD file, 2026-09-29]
docs/cad/step/MP50-A-08.stp
70.0 x 50.0 x 6.00 mm

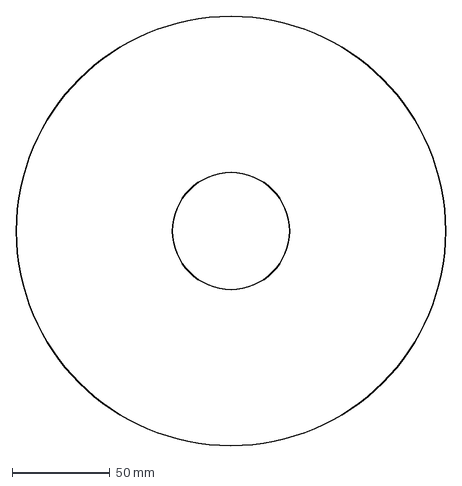
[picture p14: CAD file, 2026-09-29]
docs/cad/dxf/cut/MP50-C-B-02-CUT.dxf
220.0 x 220.0 mm

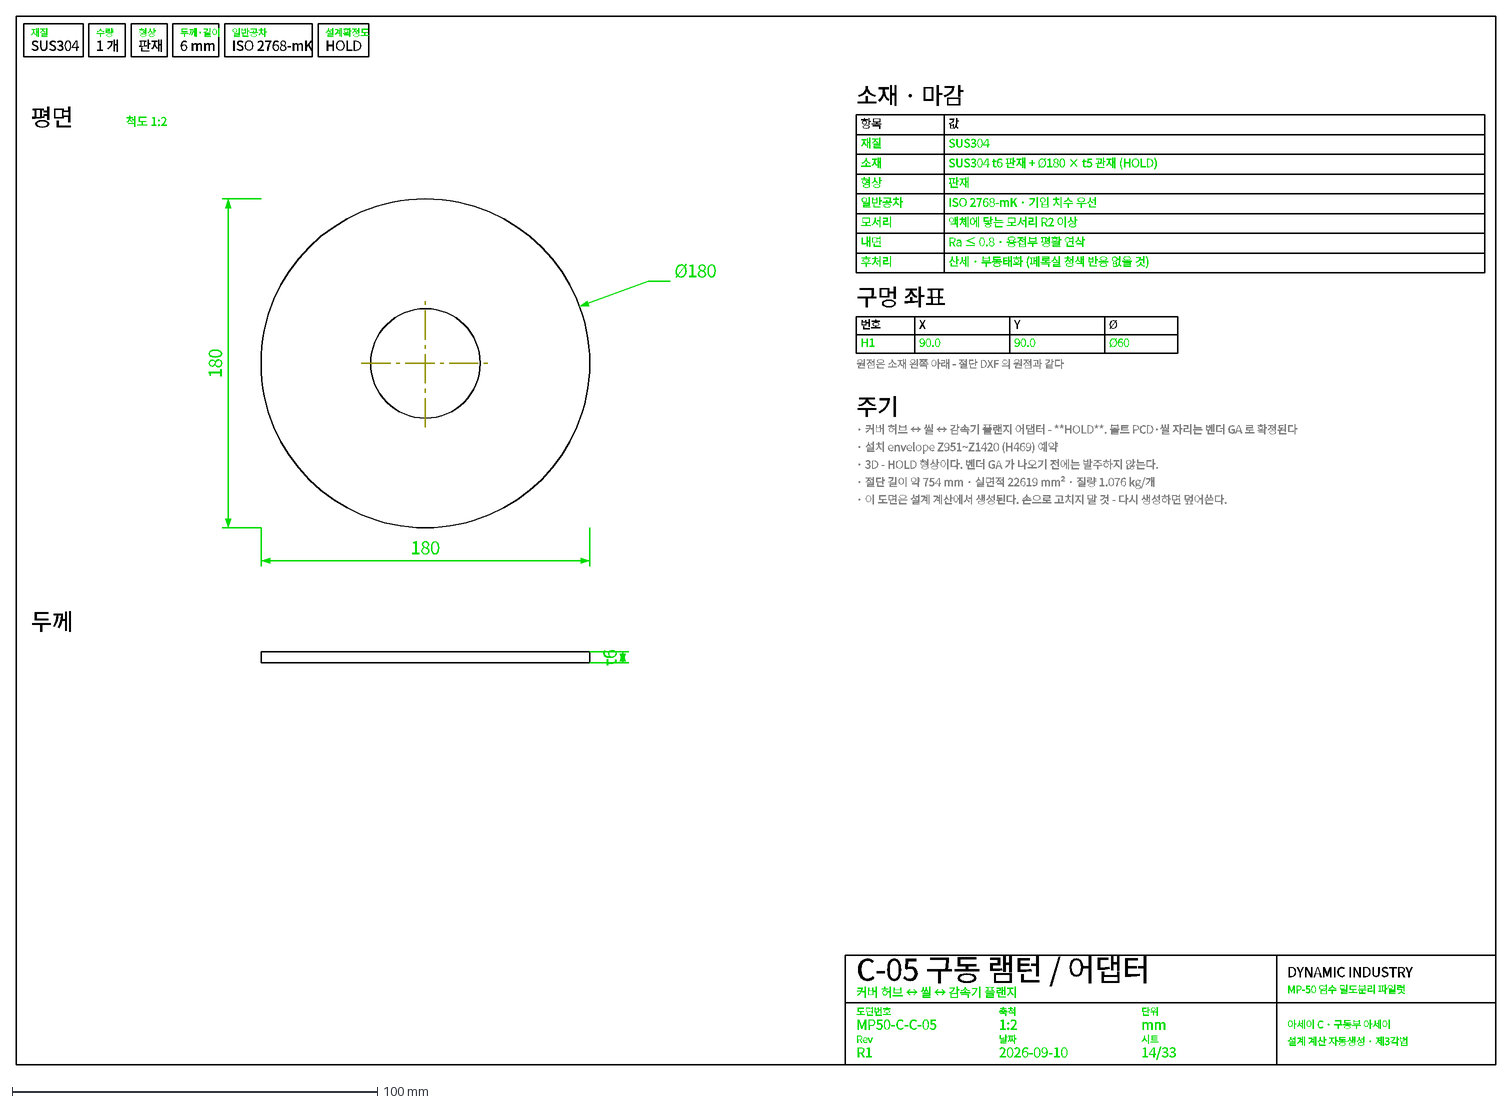
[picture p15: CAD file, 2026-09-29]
docs/cad/dxf/dwg/MP50-C-C-05.dxf
재질
SUS304
수량
1 개
형상
판재
두께·길이
6 mm
일반공차
ISO 2768-mK
설계확정도
HOLD
C-05 구동 램턴 / 어댑터
커버 허브 ↔ 씰 ↔ 감속기 플랜지
도면번호
MP50-C-C-05
축척
1:2
단위
mm
Rev
R1
날짜
2026-09-10
시트
14/33
DYNAMIC INDUSTRY
MP-50 염수 밀도분리 파일럿
아세이 C · 구동부 아세이
설계 계산 자동생성 · 제3각법
평면
척도 1:2
180
Ø180
두께
t6
소재 · 마감
항목
값
소재
SUS304 t6 판재 + Ø180 × t5 관재 (HOLD)
ISO 2768-mK · 기입 치수 우선
모서리
액체에 닿는 모서리 R2 이상
내면
Ra ≤ 0.8 · 용접부 평활 연삭
후처리
산세 · 부동태화 (페록실 청색 반응 없을 것)
구멍 좌표
번호
X
Y
Ø
H1
90.0
Ø60
원점은 소재 왼쪽 아래 - 절단 DXF 의 원점과 같다
주기
· 커버 허브 ↔ 씰 ↔ 감속기 플랜지 어댑터 - **HOLD**. 볼트 PCD·씰 자리는 벤더 GA 로 확정된다
· 설치 envelope Z951~Z1420 (H469) 예약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

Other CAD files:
docs/cad/step/MP50-D-06.stp
docs/cad/dxf/cut/MP50-C-A-05-CUT.dxf
docs/cad/dxf/dwg/MP50-C-G-02.dxf
docs/cad/step/MP50-H-02.stp
docs/cad/dxf/cut/MP50-C-A-02-CUT.dxf
docs/cad/dxf/cut/MP50-C-A-03-CUT.dxf
docs/cad/dxf/cut/MP50-C-A-04-CUT.dxf
docs/cad/dxf/cut/MP50-C-A-06-CUT.dxf
docs/cad/dxf/cut/MP50-C-A-07-CUT.dxf
docs/cad/dxf/cut/MP50-C-A-08-CUT.dxf
docs/cad/dxf/cut/MP50-C-B-03-CUT.dxf
docs/cad/dxf/cut/MP50-C-B-04-CUT.dxf
docs/cad/dxf/cut/MP50-C-B-07-CUT.dxf
docs/cad/dxf/cut/MP50-C-C-05-CUT.dxf
docs/cad/dxf/cut/MP50-C-C-06-CUT.dxf
docs/cad/dxf/cut/MP50-C-D-01-CUT.dxf
docs/cad/dxf/cut/MP50-C-D-02-CUT.dxf
docs/cad/dxf/cut/MP50-C-D-03-CUT.dxf
docs/cad/dxf/cut/MP50-C-D-06-CUT.dxf
docs/cad/dxf/cut/MP50-C-E-01-CUT.dxf
docs/cad/dxf/cut/MP50-C-E-02-CUT.dxf
docs/cad/dxf/cut/MP50-C-F-04-CUT.dxf
docs/cad/dxf/cut/MP50-C-G-01-CUT.dxf
docs/cad/dxf/cut/MP50-C-G-02-CUT.dxf
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

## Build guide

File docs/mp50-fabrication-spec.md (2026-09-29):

# MP-50 제작 기준

폐태양광 블랙파우더(31~75 µm)에서 EVA·백시트를 염수 밀도차로 걷어내는 소형 파일럿 장치. 이 문서는 `mp50_separator` 에서 자동 생성된다.

## 기준좌표

Z 원점은 원뿔의 가상 정점, θ 원점은 N1. 연구문서 Rev.0 이 따로 적어 둔 동체 상단 Z946 · 커버 상면 Z951 · 전용적 89.9 L 가 이 한 원점에서 동시에 맞는다.

| 항목 | 값 |
|---|---|
| 원뿔 가상 정점높이 | 346.41 mm |
| 원뿔대 높이 | 294.88 mm (Ø400 → Ø59.5) |
| 동체 | Z346.41 ~ Z946.41 · Ø400 ID × t3 |
| 커버 상면 | Z951.41 |
| 전용적 | 89.86 L |
| 운전 액면 | Z720 = 61.4 L |
| 운전 하한 | Z629.2 = 50 L (스키머 도달 한계) |
| 프리보드 | 226 mm |
| 동체 전개 길이 | 1266.06 mm (중립축) |
| 원뿔 전개 | R400 / R59.5 × 180° |
| 설치 높이 | 프레임 H750 · 배출면 410 · 전체 1309 |
| 질량 | 건조 151 kg · 운전 220 kg |

## 아세이

| 부호 | 도면 | 아세이 | 품목 | 개수 | 질량 kg | HOLD |
|---|---|---|---|---|---|---|
| A | MP50-A | 탱크 아세이 | 8 | 21 | 35.5 | - |
| B | MP50-B | 상부 커버 아세이 | 7 | 25 | 11.8 | 2 |
| C | MP50-C | 구동부 아세이 | 6 | 6 | 37.8 | 3 |
| D | MP50-D | 교반축 · 임펠러 아세이 | 6 | 11 | 7.2 | - |
| E | MP50-E | 배플 아세이 | 2 | 16 | 1.1 | - |
| F | MP50-F | 급기 분산링 아세이 | 5 | 18 | 0.8 | - |
| G | MP50-G | 스키머 아세이 | 4 | 6 | 1.8 | - |
| H | MP50-H | 프레임 아세이 | 7 | 30 | 27.9 | - |
| I | MP50-I | 노즐 · 배관 · 밸브 아세이 | 7 | 11 | 10.8 | - |
| J | MP50-J | 계측 · 센서 아세이 | 7 | 7 | 14.3 | - |
| K | MP50-K | 볼트 · 체결품 | 6 | 68 | 1.6 | - |

## 노즐

| 번호 | 용도 | 규격 | θ | 표고 Z |
|---|---|---|---|---|
| N1 | 급광 투입 | 1" TC | 0° | 760 |
| N2 | 부상물 배출 | 1½" TC | 90° | 735 |
| N3 | 급기 | ½" TC | 180° | 520 |
| N4C | 시료 채취 (중단) | ½" TC | 270° | 560 |
| N4A | 시료 채취 (최하단) | ½" TC | 270° | 400 |
| N4B | 시료 채취 (하단) | ½" TC | 270° | 480 |
| N4D | 시료 채취 (상단) | ½" TC | 270° | 640 |
| N4E | 시료 채취 (최상단) | ½" TC | 270° | 720 |
| N5 | 사이트글라스 | Ø100 TC | 315° | 690 |
| B1 | 구동·씰 인터페이스 | Ø220 보스 | 0° | 커버면 |
| B2 | 전도도/염도 센서 | ½" TC | 60° | 커버면 |
| B3 | 온도 RTD Pt100 | ½" TC | 180° | 커버면 |
| B4 | 예비 / 배기 | ½" TC | 300° | 커버면 |

## 제어반 J-06

임펠러와 급기의 **동시 차단**이 이 장치의 핵심 동작이다. 둘이 어긋나 멎으면 잔류 와류·기포가 층분리를 흐트러뜨려 정치 t=0 이 정의되지 않고, DOE 의 정치시간 축을 통째로 못 쓰게 된다. 운전 릴레이 CR1 의 접점 하나가 VFD RUN 과 급기 솔레노이드를 함께 물어 이를 구조로 강제한다.

| 항목 | 값 |
|---|---|
| 모터 | 0.55 kW · 4 극 · 3φ 380 V |
| 제어전원 | DC 24 V |
| 축 회전수 | 30~150 rpm |
| VFD 주파수 | 10.3~51.5 Hz |
| 감속비 | 1/10 (벤더 GA 로 확정) |
| 정지방식 | 프리런 (코스트) |
| 동시 OFF | CR1 단일 접점 — VFD RUN 과 SOL 을 함께 끊는다 |
| 급기 | 최대 10 L/min · SOL 은 NC |
| 정치시간 | 600~3600 s (CHK-10) |

### 운전 시퀀스

| 단계 | 이름 | 임펠러 | 급기 | 무엇이 끝내나 |
|---|---|---|---|---|
| S1 | 장입 | 정지 | 닫힘 | 수동 |
| S2 | 분산 | 운전 | 열림 | TIM1 시간종료 |
| S3 | 동시 OFF | 프리런 정지 | 즉시 닫힘 | 즉시 (같은 접점) |
| S4 | 정치 | 정지 | 닫힘 | TIM2 시간종료 |
| S5 | 회수 | 정지 | 닫힘 | 수동 |

### 감속비

표준 감속비 가운데 축 150 rpm 을 낼 수 있는 것은 1/10 뿐이다. 1/20 은 상용주파수에서도 87 rpm 에 그치는데, 이것이 [R] 이 적은 상한 90 rpm 의 정체로 보인다 (CHK-05).

| 감속비 | 60 Hz 축속 | 30 rpm 주파수 | 판정 |
|---|---|---|---|
| 1/10 | 175 rpm | 10.3 Hz | 가능 |
| 1/15 | 116 rpm | 15.5 Hz | 불가 — 150 rpm 못 냄 |
| 1/20 | 87 rpm | 20.6 Hz | 불가 — 150 rpm 못 냄 |

### 단자

| 단자 | 종류 | 명칭 | 접속처 | 비고 |
|---|---|---|---|---|
| L1·L2·L3·PE | 전원 | 주회로 입력 | 배전반 380 V 3φ | MCCB 1 차. 누전차단 30 mA |
| U·V·W·PE | 전원 | VFD 출력 → 모터 | C-01 기어드 모터 | 차폐 케이블. 실드는 반 쪽 1 점 접지 |
| 24V·0V | 전원 | 제어전원 DC 24 V | SMPS 2 차 | 젖은 자리라 제어는 저전압으로 내린다 |
| X1·X2 | DI | 운전 (자기유지 기동) | PB1 녹색 a 접점 | 누르면 CR1 여자 · 자기유지 |
| X3·X4 | DI | 동시 OFF (수동) | PB2 적색 b 접점 | CR1 유지회로를 연다 — 조기 차단용 |
| X5·X6 | DI | 비상정지 | EMS 버섯형 b 접점 2 회로 | 제어전원을 끊는다. 복귀는 수동 |
| Y1·Y2 | DO | VFD RUN 지령 | VFD DI1 (무전압 a 접점) | CR1-1. 떨어지면 프리런 정지 |
| Y3·Y4 | DO | 급기 솔레노이드 | SOL 코일 DC 24 V | CR1-2. NC 형이라 소자되면 닫힌다 |
| Y5·Y6 | DO | 정치 t=0 마크 | J-07 로거 DI | CR1-3. 로거에 차단 시각을 찍는다 |
| X7·X8 | DI | 사이클 리셋 | PB3 청색 b 접점 | CR2 래치를 푼다. 다음 배치 전에 누른다 |
| Y7·Y8 | DO | 정치 종료 부저·램프 | BZ1 · PL3 | TIM2 시간종료 — 배출 준비 |
| A1·A2 | AO | VFD 전류 출력 4~20 mA | J-07 로거 AI | [R] §15 필수 데이터. 분산 상태의 상시 신호 |
| A3·A4 | AI | 속도 지령 (선택) | VFD AI1 | 반 전면 포텐셔미터. 조건표 회전수를 맞춘다 |

### 제어반 구성품

| 기호 | 품명 | 사양 | 수량 |
|---|---|---|---|
| QF1 | 주차단기 | 3P 380 V · 누전차단 30 mA · 10 A | 1 |
| INV | VFD | 정토크 0.55 kW 이상 (프레임 0.75 kW) · 3φ 380 V | 1 |
| PS1 | SMPS | DC 24 V 2 A | 1 |
| CR1 | 운전 릴레이 | DC 24 V · 4a 접점 | 1 |
| TIM1 | 분산 타이머 | ON 딜레이 0.1~99.9 분 | 1 |
| CR2 | 사이클 래치 | DC 24 V · 2a 접점 | 1 |
| TIM2 | 정치 타이머 | ON 딜레이 1~9999 s (600~3600 격자) | 1 |
| PB1 | 운전 버튼 | 녹색 a 접점 · 램프 내장 | 1 |
| PB2 | 동시 OFF 버튼 | 적색 b 접점 · Ø30 | 1 |
| PB3 | 리셋 버튼 | 청색 b 접점 | 1 |
| EMS | 비상정지 | 버섯형 래치 · b 접점 2 회로 | 1 |
| SOL | 급기 솔레노이드 | 2 포트 NC · DC 24 V · ½" | 1 |
| PL1~3 | 표시등 | DC 24 V · 전원 / 운전 / 정치종료 | 3 |
| BZ1 | 부저 | DC 24 V | 1 |
| VR1 | 속도 설정기 | 1 kΩ 포텐셔미터 + 눈금판 | 1 |

## 원본 치수 충돌

[R] 연구문서 Rev.0 · [D1] MP-50-P0-001 · [D2] MP50-DR-000 의 치수가 서로 어긋난다. BLOCKING 은 그대로 두면 조립이 되지 않는 항목이다.

| 번호 | 항목 | 등급 | 채택값 | 상태 |
|---|---|---|---|---|
| C1 | 원뿔 높이 | BLOCKING | 가상 정점높이 346.41 · 실제 원뿔대 높이 294.88 (Ø400 → Ø59.5) | 확정 |
| C2 | 배플 폭 | BLOCKING | 35 W × 300 L × t3 × 4매, 벽 이격 6, Z390~690 | 승인 필요 |
| C3 | 콘 배출 스터브 | MAJOR | 2 in 위생튜브 Ø63.5 × t2.0 (ID 59.5) + 2" 페룰 | 승인 필요 |
| C4 | 분산링 지름 · 노즐 | MINOR | PCD Ø250 · Ø12 × t1.5 튜브 · Ø1.5 홀 12개 (하향) | 승인 필요 |
| C5 | 분산링 명칭 | MINOR | 급기 분산링 (Air sparger ring) | 승인 필요 |
| C6 | 운전 장입량 | MAJOR | 운전 장입 61.4 L (Z720) · 하한 50.0 L (Z629) | 확정 |
| C7 | 계측 구성 | MAJOR | 전도도(염도) · 온도 RTD · 공기 로타미터 · 시료 사다리 5단 | 승인 필요 |
| C8 | 상부 커버 체결 | MINOR | 플랜지 OD Ø480 · PCD Ø450 · M12 × 12 · 면 홈에 EPDM O-링 | 승인 필요 |

## 설계 검증

**조립** 항목은 부품끼리 부딪히지 않는지를 본다 — 하나라도 FAIL 이면 발주할 수 없다. **기능** 항목의 WARN 은 장치가 아니라 운전조건·시험계획을 고치라는 뜻이다.

| 번호 | 구분 | 항목 | 결과 | 판정 |
|---|---|---|---|---|
| CHK-01 | 조립 | 원뿔 폐합 · 전용적 | 높이 294.88 · 전용적 89.86 L | PASS |
| CHK-02 | 조립 | 임펠러 ↔ 배플 간극 | 공칭 9.0 · 최악 7.5 mm | PASS |
| CHK-03 | 조립 | 분산링 ↔ 콘 벽 | 공칭 42.2 · 최악 39.2 mm | PASS |
| CHK-04 | 조립 | 스키머 반출 | 편측 간극 50 mm | PASS |
| CHK-05 | 기능 | 완전분산 회전수 (Njs) | Njs 135 rpm (최대배치 3 kg · NaCl 18 wt% · 75 µm) | WARN |
| CHK-06 | 기능 | 구동 토크 | 소요 17.1 N·m · 0.37 kW → 16.5 · 0.55 kW → 24.5 N·m | PASS |
| CHK-07 | 조립 | 축 1 차 위험속도 | 1399 rpm (운전 150 rpm 의 9.3 배) | PASS |
| CHK-08 | 기능 | 급기 분배 · 기포 지름 | 오리피스 7.9 m/s · 링 1.31 m/s · 비 6.0 · 기포 Ø3.9 mm | PASS |
| CHK-09 | 조립 | 배출부 여유 | 260 mm (배출면 410) | PASS |
| CHK-10 | 기능 | 정치 600 s 도달률 | 최저 백시트 31 µm 1 % | WARN |
| CHK-11 | 기능 | Stokes 적용 타당성 | Re 0.117 (Si 75 µm, 2.24 mm/s) | PASS |
| CHK-12 | 조립 | 프리보드 | 226 mm (액면 Z720 → 동체 상단 Z946) | PASS |
| CHK-13 | 조립 | 프레임 하중 · 전도 | 운전질량 220 kg (건조 151 kg) · 비 0.31 | PASS |
| CHK-14 | 기능 | 시료 사다리 피복 | 5 단 Z400~Z720 · 간격 80~80 mm · 피복 86 % | PASS |

### CHK-05 완전분산 회전수 (Njs) — WARN

Zwietering 상관식이 135 rpm 을 요구하는데 감속기 상한은 90 rpm 이라 여유가 없다. 다만 이 상관식은 무기포·평저 기준이고 D/T 0.75 는 검증범위(0.2~0.5) 밖이므로 135 을 정확한 값으로 읽으면 안 된다. **조치 — 감속기 최고속도를 150 rpm 까지 확보한다.** 축·동력·위험속도는 CHK-06/07 에서 150 rpm 으로 검증했다. 실측 후 낮추는 것은 언제든 되지만, 납품 후 올리는 것은 감속기 교체다. 콘 정착층은 분산링(F)의 gas lift 가 함께 받는다.

### CHK-10 정치 600 s 도달률 — WARN

액주 668 mm (콘 포함 61.4 L), NaCl 18 wt% 기준 — 부피 균등분포로 세면 Si 75 µm +2.243 mm/s → 100 % · Si 31 µm +0.383 mm/s → 13 % · EVA 75 µm -0.404 mm/s → 50 % · EVA 31 µm -0.050 mm/s → 6 % · 백시트 31 µm -0.008 mm/s → 1 %. Si 는 문제가 없지만 **미세 폴리머가 뜨지 않는다**: 31 µm EVA 는 600 s 에 6 % 만 표면에 닿고, 31 µm 백시트는 Δρ 가 -25 kg/m³ 뿐이라 사실상 움직이지 않는다. Stokes 는 d² 로 가므로 미세분은 시간이 제곱으로 든다. 이건 장치 결함이 아니라 시험계획 문제이며, **장치를 고치지 말고 두 가지를 바꾼다** — (1) [R] §11 의 정치시간 격자 60~600 s 를 600~3600 s 로 넓힌다. (2) 염도 격자에 22/26 wt% 를 넣는다: 포화까지 올리면 31 µm 백시트의 상승속도가 0.0081 → 0.022 mm/s 로 2.7 배가 된다 (밀도차는 3.6 배지만 점도도 함께 올라 이득이 그만큼은 아니다). 단 포화 염수까지 갈 경우 동체 재질은 SUS304 가 아니라 SUS316L 이어야 한다.

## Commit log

2026-08-24 태양광 재활용용 단단 부유선별기 설계 (Ag/Cu, 0.3/0.5 t/h)
    폐 c-Si 모듈 셀 분획에서 은·구리를 회수하는 1단 기계식 강제급기
    부선셀의 설계 사양서와 사이징 계산 코드를 추가한다.
    설계 결과:
    - 셀 내부 700 x 700 x 810 mm(H), 유효 슬러리 체적 0.281 m3
    - 체류시간 16.5 min @ 0.30 t/h, 9.9 min @ 0.50 t/h
    - 로터 Ø240 mm / 440 rpm / 2.2 kW VFD, 급기 Jg 1.0 cm/s (Sb 50 1/s)
    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
2026-08-24 CI: 테스트 및 계산서 동기화 검증 워크플로 추가
    - unittest: Python 3.10/3.11/3.12 매트릭스로 테스트 80건 실행
    - calculation-report: docs/design-calculation.md 를 재생성해 커밋된
    파일과 diff 를 비교. 설계 기준을 고치고 계산서를 갱신하지 않으면
    실패하므로, 문서와 코드가 어긋난 채 머지되는 것을 막는다.
    Claude-Session: https://claude.ai/code/session_019CzgvrLDgmX2A2VeSiFmYk
2026-08-24 스캐빈저·클리너 추가 — 러퍼 단독에서 3단 순환 회로로 확장
    러퍼 단독 구성은 회수율이 r_max 에 점근할 뿐이고 정광에 Si 가 24%
    동반되는 한계가 있었다. 스캐빈저 FC-102 와 클리너 FC-103 을 붙여
    순환 폐회로로 확장한다.
    성능 (최대 0.5 t/h 기준, 러퍼 단독 대비):
    - Ag 회수율 70.7% -> 75.7%, Cu 84.8% -> 91.3%
    - 정광 Ag 품위 1.88% -> 2.79% (농축비 6.2배)
    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
2026-08-24 리뷰 반영: 문서화된 실행 명령·처리량 재정의 표시 수정
    Codex 리뷰 3건 반영.
    1. (P2) 문서의 `python -m flotation_design` 이 신규 체크아웃에서
    ModuleNotFoundError 로 실패했다. src 레이아웃이라 PYTHONPATH 가
    필요한데 테스트만 tests/_path.py 로 우회하고 있었다.
    README·설계문서·CLI docstring·CI 안내문의 모든 명령에
    PYTHONPATH=src 를 붙이고, 문서의 bash 코드블록에서 명령을 추출해
    실제로 실행해 보는 회귀 테스트를 추가했다.
    2. (P1) --peak-tph 로 처리량을 바꿔도 셀은 design_basis 의 확정
    치수 그대로였는데, 계산서가 이를 드러내지 않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
2026-08-24 문헌 실증 데이터로 전면 재설계 — 연속 부선조 1단
    Saffarian, Galvin & Firouzi 의 실증 논문 두 편을 반영해 설계를 다시
    세웠다. 문헌 없이 일반 광물부선 관행으로 추정했던 이전 판의 전제
    상당수가 틀렸다.
    [1] Minerals Engineering 242 (2026) 110189 — 회분식 실증
    [2] ChemRxiv 2026, doi:10.26434/chemrxiv.15003814/v1 — 연속 실증
    주요 정정:
    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
2026-08-24 설계도 3매 추가 — 공정 흐름도 · 부선조 단면 · 대안 비교
    docs/drawings/ag-flotation-drawings.html (단독 HTML, 인라인 SVG).
    - DWG-001 공정 흐름도: 급광 → CT-1 → FC-101 → 정광/미광 계통과
    공정수 순환. 스트림 6개 번호와 물질수지 표 포함.
    - DWG-002 부선조 상세 단면: 런더·세척수 분배관·거품층·스파저·
    경사판·미광 배출을 수직 단면으로 그리고, flux 4개(Jf/Jg/Jw/Jo)와
    bias 를 화살표로 표시. 계장은 bias 연산기 FFIC-106 중심.
    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
2026-08-24 3D 컷어웨이 모델 추가 — FC-101 / FC-201
    docs/drawings/ag-flotation-3d.html (단독 HTML, 외부 라이브러리 없이 WebGL 직접 구현).
    - 마우스 드래그 회전 / 휠 확대, 컷어웨이 슬라이더, 부위 명칭 토글
    - FC-101 은 세장형 컬럼이라 근접 절반 절단, FC-201 은 4분면 절단
    - 절단 쐐기를 카메라 방위각 기준으로 잡아 열린 면이 항상 시점을 향한다
    - 로터·스테이터·축·스파저는 절단 제외 — 내부 기구가 온전히 드러나야 한다
    - 형상은 파라메트릭 프리미티브(회전체·박스·파이프·토러스)로 생성
    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
2026-08-24 2안을 3단(러퍼·스캐빈저·클리너)으로 확장 + 부품 분해 3D 모델
    기계식 대안을 '러퍼 뱅크 2기 + 클리너' 에서 '러퍼 → 스캐빈저 →
    클리너' 3단으로 바꾸고, 3D 모델을 부품 분해가 가능한 3셀 스키드로
    다시 만들었다.
    이전 판에서 스캐빈저를 뺀 판단이 과했다. 실제로 계산해 보면
    스캐빈저 단독 Ag 회수율이 73.0 % 이고 회로 기여가 +4.4 %p 다.
    성능 (최대 0.50 t/h):
    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
2026-08-24 중공축 급기 설계 + 필터프레스 탈수 라인 추가
    급기를 셀 바닥 스파저가 아니라 로터 축 내부로 넣는 구성으로 바꾸고,
    정광·미광 양쪽에 필터프레스 탈수 라인을 붙였다.
    중공축 급기 (sizing.hollow_shaft)
    - 보어는 축 내부 공기 유속(목표 18 m/s)으로, 외경은 비틀림 강도와
    세장비 L/D <= 25 중 큰 쪽으로 정한다. 세 셀 모두 세장비가 이겼다 —
    전단응력이 허용치의 2.5 % 도 안 된다.
    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
2026-08-24 셀별 상세도면 3매 + 여액 러퍼 순환 + 수치해석 (수력학 검산·기동 ODE)
    요청 반영 세 가지.
    여액 → 러퍼 순환
    - 필터프레스 여액 0.47 m3/h 를 공정수 탱크가 아니라 부선 회로 첫 단
    급광(1안 CT-1, 2안 FC-201)으로 직접 되돌린다 — 여포를 빠져나온
    미립 Ag 에 한 번 더 부선 기회를 주기 위해서다.
    - plant.py 에 filtrate_m3h / filtrate_return_to 프로퍼티, DWG-001 에
    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
2026-08-25 설계 검토 지적사항 수정 및 물수지 검증
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2026-09-03 DG-HK60 3D 운전 콘솔 — 전문 상업장비 수준으로 재작업
    PV 분리설비 3D 뷰어를 평면 아이소메트릭 도해에서 실제 상용장비 렌더와
    운전 콘솔 수준으로 끌어올렸다.
    렌더 엔진
    - 3점 스튜디오 라이팅(키·필·반구 앰비언트)과 리버리 색상별 표면 마감(MATS)
    도입. 단일 광원 밝기 배율을 대체해 도장강판·가공금속·유리가 구분된다.
    - 높이·하향면 기반 앰비언트 오클루전, Blinn-Phong 하이라이트,
    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
2026-09-03 콘솔을 라이트/다크 양쪽에 대응
    기존 도면 두 건과 같은 규약을 따라 :root 를 라이트 기본으로 두고,
    @media (prefers-color-scheme: dark) 와 [data-theme="dark"] 로 덮는다.
    - CSS를 전면 토큰화. 버튼 그라디언트, HUD 유리판, 명판, 대화상자, 경고
    박스 등 색을 직접 박아두던 규칙을 모두 변수로 옮겼다. 이제 색을 정의하는
    곳은 :root 와 두 개의 다크 블록뿐이다.
    - 캔버스는 CSS 변수를 읽을 수 없으므로 JS 쪽에 ENV 팔레트를 두 벌 만들었다.
    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
2026-09-03 부품 지지·장착 구조를 실제 하중경로로 표현
    구조 기둥이 바닥에서 400~600mm 떠 있었고, 베이스 플레이트·베어링 하우징·
    덕트 지지가 전혀 없었다. 부재는 그려져 있으나 무엇이 무엇을 받치는지가
    빠져 있어 개념 스케치로 읽혔다.
    지지 부재 라이브러리
    - column: 바닥까지 내려오는 기둥 + 그라우트 베이스 플레이트 + 앵커볼트
    - gusset: 기둥과 보가 만나는 곳의 삼각 무릎보강
    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
2026-09-03 DYNAMIC INDUSTRY 아이덴티티 정의 및 장비·콘솔 적용
    마크는 오른쪽 위로 올라가는 세 개의 전단된 바다. 이 설비가 내보내는 세 계통
    — 백시트, 셀/EVA, 판유리 — 과 그것들이 분리되는 동안 패널이 지나가는 방향을
    같이 담았다. 하나의 기하로 장비 외장(3D 폴리곤)과 콘솔 크롬(SVG)을 모두
    그리므로, 캐비닛에 붙은 배지와 헤더에 있는 배지는 말 그대로 같은 도형이다.
    3D 각인 서체
    - 6×10 격자 단선 대문자 서체를 넣어 장비면 레터링을 3D 선분으로 그린다.
    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
2026-09-03 실제 DYNAMIC INDUSTRY 로고로 교체
    지급받은 로고 아트워크에서 도형과 색을 직접 추출해, 임시로 만들었던 마크를
    실제 회사 마크로 바꿨다.
    추출
    - 이미지를 색상 마스크로 분리하고 연결요소를 찾아, 각 요소의 볼록껍질을
    Visvalingam-Whyatt 로 단순화해 폴리곤 5개(파랑 4·노랑 1)를 얻었다.
    - 벡터를 다시 래스터화해 원본과 대조: 픽셀 일치 97.7%. 차이는 라운드 코너가
    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
2026-09-03 콘솔이 호스트가 지정한 테마를 따르도록 보정
    아티팩트 프레임이나 문서 셸처럼 이미 <html data-theme>를 찍어둔
    호스트 안에 임베드되면, '자동' 모드가 그 표식을 지우고 OS 설정으로
    되돌아간다. 호스트에 다크를 요청한 사람에게 라이트가 보이는 문제라
    초기 로드 시 호스트가 찍어둔 값이 있으면 그것을 초기 선호도로 채택한다.
    사용자가 직접 고른 값(localStorage)이 있으면 그쪽이 계속 우선한다.
    Claude-Session: https://claude.ai/code/session_01LxD4TdMj9SYXLqNMi3cCAX
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2026-09-03 명판 정격을 전기부하표에서 유도하도록 수정
    어제 명판에 IEC 60204-1 16.4 표시를 넣으면서 값 자체는 검증하지
    않았다. 셋 다 문제가 있었다.
    482A: 라벨이 틀렸다. 이 값은 연결부하가 아니라 예상 최대수요
    270kW 를 역률 0.85 로 나눈 수요전류다. 명판의 FLA 는 전부하전류이지
    수용률을 적용한 값이 아니다. 이걸 보고 케이블을 고르면 과소 선정된다.
    50KA: 도면이 스스로 "Icu 는 단락계산 후 확정" 이라고 적어둔 값을
    근거 없이 각인했다. 500kVA·임피던스 5~6% 기준 예상 단락전류는
    12.7~15.2kA 다.
    42T: 문서 어디에도 질량 값이 없다. 만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
2026-09-03 Codex 리뷰 지적 3건 수정
    전부하전류를 위상합으로 계산. 직전 커밋에서 "총 kW 를 혼합역률로
    나누면 틀린다" 고 쓰면서 대신 쓴 분기전류 산술합도 반대 방향으로
    틀렸다. 역률이 서로 다른 전류를 크기만 더하면 각도가 다른 무효분을
    같은 방향으로 취급해 과대평가된다.
    유효 318.0 kW · 무효 68.5 kvar → 피상 325.3 kVA
    494.2 A (계통 역률 0.978) ← 물리적으로 맞는 값
    508.6 A ← 산술합, +2.9% 과대
    568.4 A ← 총 kW ÷ 가정 역률 0.85, 과소
    명판 FLA 509A → 494A. 표에 적었던 "등가역률 0.950" 은 역률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
2026-09-04 아티팩트 생성기를 저장소에 보관 — 저장소 파일이 원본, 아티팩트는 여기서 찍는다
    저장소 HTML 의 <title>·<style>·<body> 안쪽만 기계적으로 옮긴다. 내용을
    만들거나 바꾸지 않는지 변환 후 assert 로 확인한다. 두 벌을 따로 고치면
    반드시 갈라지므로, 수정은 저장소를 고치고 이 스크립트로 다시 찍는 순서다.
    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
2026-09-05 3D 홀을 18.76m 압축 배치로 다시 세우다
    D-601 도면만 고치고 홀은 53m 인 채로 두면 같은 콘솔 안에서 두 개정이 서로
    다른 기계를 말하게 된다. 홀도 같은 상수(COMPACT_STATIONS)에서 세웠다.
    · 패널이 서고 칼날이 간다. VT-101 6존 고정 진공테이블에 패널을 앉히고
    KG-101 갠트리가 2,400mm 를 55mm/s 로 지나간 뒤 2,700mm 를 700mm/s 로
    돌아온다. 11.2m 이송축이 3.8m 셀이 됐다.
    · 유리 냉각을 5단 랙으로 세웠다. 가열실과 같은 cRack 으로 그려 랙·포크·
    예비품이 한 벌이면 된다는 판단이 코드에도 남는다.
    · 환경설비·후속파쇄·팔레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
2026-09-07 해석기에서 numpy 를 걷어내다 — 시험은 빈 인터프리터에서 돈다
    CI 가 세 파이썬 버전에서 전부 죽었다. unittest 잡은 **아무것도 설치하지
    않는다** — pyproject 의 dependencies 가 비어 있고 numpy 는 simulation
    부가의존으로 격리돼 전용 잡에서만 돈다. 해석기를 numpy 로 짜면서 그
    성질을 깼고, 로컬에는 numpy 가 있어 920건이 통과했으므로 **로컬 통과가
    보증이 아니었다.**
    격리하는 쪽(skipUnless + 전용 잡)이 더 싸지만 그렇게 하지 않았다.
    flotation_sim 은 선택 도구라 격리가 맞지만, 구조·열해석은 부품
    카탈로그가 바뀔 때마다 다시 풀려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
2026-09-24 CAL-001 순생산을 사양서와 맞추고, 압축 계열의 '권취 대기' 카드를 실제로 숨긴다
    - analysis_irbank: 처리량을 반올림 전 택트로 낸다. 표시용 54.3 s 로 나눈 59.7 장/h 가
    사양서·콘솔의 59.6(cycle.RATE_NET) 과 갈라졌다. test_irbank 가 칼날이 처리량을 정할 때
    두 값이 같은지 본다. 재생성: dg-hk60-analysis.
    - 콘솔: 압축·트윈에서 백시트 카드에 hidden 을 켰지만 .flow-item 의 display:flex 가 이겨
    철거한 권취부의 '권취 대기 → 전용 보관함' 이 그대로 떠 있었다. [hidden] 을 명시하고
    반출 칸을 둘로 줄인다(좁은 화면은 한 줄 그대로). Rev.20 은 셋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
2026-09-29 부품도를 CAD 로 낸다 — 자를 파일, 가공도, 3D 솔리드
    HTML 부품도는 사람이 읽는 것이다. 현장은 그것으로 자르지 못한다. 레이저
    오퍼레이터는 닫힌 윤곽을 먹는 파일이 필요하고, 가공장은 지름과 축을 읽을 수
    있는 해석면 솔리드가 필요하다. 제작품 33 종을 세 갈래로 낸다.
    docs/cad/dxf/cut/ 절단 윤곽만. 1:1, 글자 한 자 없음, 원점은 소재 왼쪽 아래
    docs/cad/dxf/dwg/ A3 가공도. 틀·표제란·치수·구멍 좌표표·절곡표·주기
    docs/cad/step/ 3D 솔리드 (AP214). 평면·원통·원뿔 해석면
    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
    [MP50-A-01.stp, MP50-A-02.stp, MP50-A-03.stp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]
